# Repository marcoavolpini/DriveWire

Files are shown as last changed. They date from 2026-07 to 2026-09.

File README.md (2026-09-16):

# DriveWire

### A hardware-tested ESP32-S3 rover for embedded control, vehicle telemetry, and power-electronics development

DriveWire is a scaled-down electric vehicle test platform built to take an embedded system from breadboard bring-up to a custom PCB running FreeRTOS software. The current prototype drives two brushed DC motors, measures electrical and distance telemetry, and runs sensor acquisition in a periodic FreeRTOS task. Development is now focused on replacing the lossy prototype power path with a protected 2S LiPo power architecture that has been fully designed in Altium.

> **Status - September 2026:** the breadboard prototype and core firmware have been exercised on hardware. The custom power schematic is completed and needs to be laid out, fabricated, and validated. Telemetry currently runs over serial; Wi-Fi control and a browser dashboard are planned.

<p align="center">
  DriveWire ESP32-S3 rover prototype
</p>

## Engineering snapshot

| Area | Implemented and tested | In progress / next |
|---|---|---|
| Embedded firmware | PlatformIO/Arduino firmware, bidirectional motor control, braking/coasting, 17.5 kHz PWM, INA219 and VL53L0X drivers | Control interface, system-level safety logic, encoder feedback |
| Real-time telemetry | 100 ms FreeRTOS sensor task, single-item queue, voltage/current/power/distance state, last-valid-data behavior on failed reads | Recovery after sensor power cycling, telemetry transport over Wi-Fi |
| Electrical | 2S LiPo bench testing, current/voltage capture, stall-current characterization | Altium PCB power path, regulated 6 V and 3.3 V rails, component-value validation |
| Mechanical | Assembled 2WD chassis; three SolidWorks stand iterations; final stand printed in PLA and fit-tested | Dedicated sensor and battery mounting |

## Measured engineering evidence

- **Motor-current characterization:** two repeatable stall captures measured **1.3414 A** and **1.3308 A** using the onboard INA219. The firmware sampling period was reduced to 100 ms and the resulting trace was plotted in MATLAB to inform PCB current ratings.
- **Power-loss isolation:** during stall, INA219 telemetry fell to approximately **6.39 V**, but a DMM at the battery-connected rails measured only **7.78 V to 7.34 V**. This indicates that much of the observed drop is in the breadboard/prototype current path, which is now a design input for the PCB rather than an assumed battery failure.
- **PWM investigation:** a hardware sweep from 1 kHz to 18 kHz tied the audible motor tone to PWM carrier frequency. **17.5 kHz at 8-bit resolution** was selected and verified on both motors at full duty.
- **Sensor robustness:** failed INA219 or ToF reads mark the device offline without overwriting the previous valid telemetry. The VL53L0X produced reliable readings to approximately **1.3 m** under the tested indoor conditions.
- **Mechanical iteration:** the support stand progressed through three SolidWorks revisions before an approximately nine-hour PLA print; the finished part securely suspends the wheels for repeatable bench testing.

<p align="center">
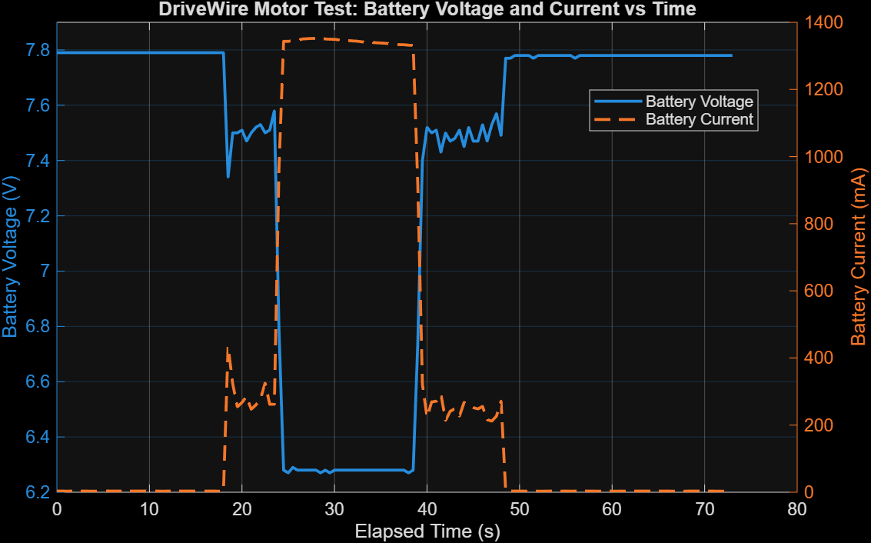
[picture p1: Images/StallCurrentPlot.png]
Measured DriveWire battery voltage and current during a motor stall test
  
</p>

## Current prototype architecture

```mermaid
flowchart LR
    LIPO[2S LiPo] --> PATH[Prototype power path]
    PATH --> INA[INA219 voltage/current sensing]
    PATH --> DRV[DRV8833 motor drive]
    DRV --> MOTORS[Left and right DC motors]
    ESP[ESP32-S3] -->|17.5 kHz PWM| DRV
    INA -->|I2C| ESP
    TOF[VL53L0X distance sensor] -->|I2C| ESP
    ESP --> TASK[100 ms FreeRTOS sensor task]
    TASK --> QUEUE[Latest-state queue]
    QUEUE --> SERIAL[Serial telemetry]
```

The firmware keeps commanded motor values, sensor readings, device status, and safety flags in a shared `DriveWireState`. The sensor task refreshes an independent state snapshot and publishes it through a one-element queue with `xQueueOverwrite()`, so the main loop reads a complete latest-value copy rather than partially updated telemetry.

## Custom power-system direction

The first Altium design translates lessons from the prototype into a board-level power path. The present schematic includes a 5 A fuse concept, PMOS reverse-polarity protection, a low-current mechanical switch controlling a power MOSFET, INA219 current sensing, and a TPS2121-based motor-rail concept with regulated 6 V and 3.3 V branches.

These are **design-stage features**, not validated hardware. Shunt value, I2C pull-ups, protection thresholds, regulator implementation, thermal performance, layout, and the complete safety review remain open before fabrication.

<p align="center">
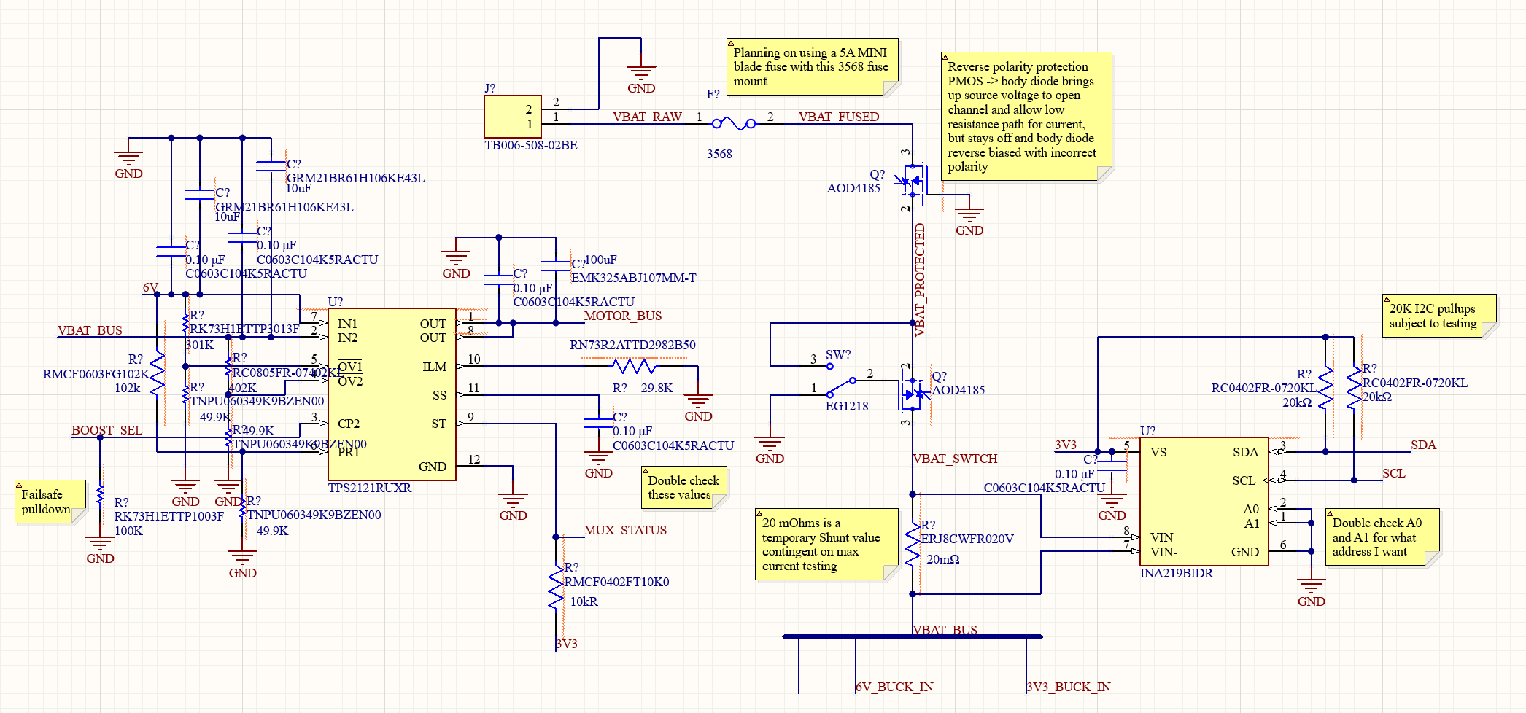
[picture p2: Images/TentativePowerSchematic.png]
In-progress DriveWire Altium power schematic
  
</p>

## Repository guide

| Path | Contents |
|---|---|
| [`Firmware/`](Firmware/) | PlatformIO project, motor control, sensor drivers, FreeRTOS task, and hardware test files |
| [`Hardware/`](Hardware/) | Altium project, power-design notes, datasheets, MATLAB test data, and plots |
| [`Mechanical/`](Mechanical/) | Chassis, battery wiring, and SolidWorks/3D-print documentation |
| [`BuildLog.md`](BuildLog.md) | Dated build history with test results, photos, and design decisions |
| [`Debugging.md`](Debugging.md) | Fault isolation, failed hypotheses, and resolved issues |
| [`BOM.md`](BOM.md) | Prototype bill of materials and status |

## Build the firmware

The firmware targets an **ESP32-S3-DevKitC-1** with Arduino through PlatformIO.

```bash
cd Firmware
pio run
pio device monitor -b 115200
```

The upload and monitor ports in [`Firmware/platformio.ini`](Firmware/platformio.ini) are workstation-specific and may need to be changed.

## Project scope

DriveWire is an active engineering project. The short-term milestones are to validate the power schematic, complete PCB layout, validate the protection and regulator stages, then integrate wireless control and closed-loop motion sensing. The distinction between bench-verified behavior and planned capability is maintained throughout this README and the build log.

---

<strong>Marco Volpini</strong><br>
Electrical Engineering, University of Waterloo

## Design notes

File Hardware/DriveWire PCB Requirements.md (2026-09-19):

**DriveWire PCB**

**6 V Buck Converter**

* Must take 6-8.4 V input from the LiPo pack
* Stall current was measured at consistently under 1.4 A with a 7.8 V charged battery, so being able to handle ideally >= 4 A 
* Needs to be pretty stable output for motor load (affects capacitor choice as well)

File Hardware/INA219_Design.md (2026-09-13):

# INA219 Hardware Design

I selected the INA219BIDR chip for this project because of its SOIC-8 form factor and of its higher accuracy as it is B grade rather than A. 

## Selecting a Shunt Resistor
First step is determining the expected max current I will need to sense.

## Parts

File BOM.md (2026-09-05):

# Bill of Materials

| Component | Purpose | Status |
|---|---|---|
| ESP32-S3 DevKitC-1-N8R8 | Main controller | In use |
| Pololu DRV8833 dual motor driver | Dual DC motor control | In use/testing |
| 2WD robot chassis | Mechanical platform | Assembled |
| DC gear motors | Propulsion | Wired |
| AA battery pack | Motor power | In use |
| Adafruit current sensor | Motor current measurement | Soldered, in use |
| Adafruit ToF sensor | Distance sensing | Soldered, in use |
| 22 AWG automotive wire | Motor and power wiring | In use |
| Heat shrink tubing | Joint insulation/strain relief | In use |
| LiPo 2S Battery Pack | Power source | In progress |

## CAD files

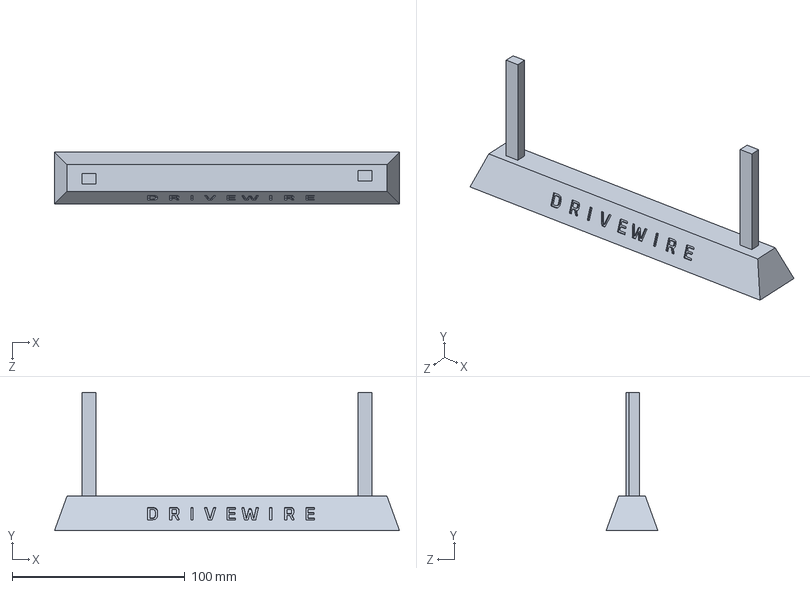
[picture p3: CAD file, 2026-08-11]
Mechanical/CAD/Support Stand/DriveWireStand.SLDPRT
200.0 x 80.0 x 30.0 mm

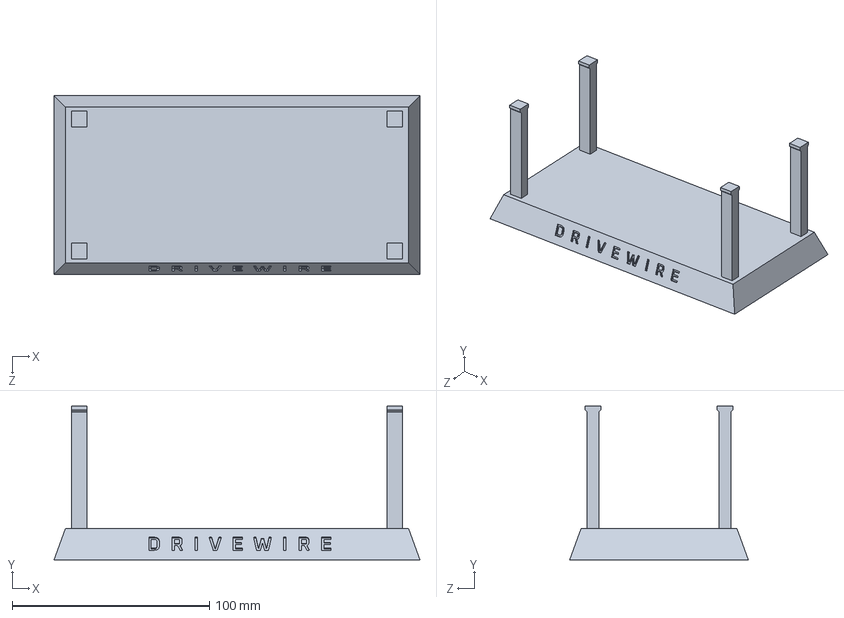
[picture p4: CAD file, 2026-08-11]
Mechanical/CAD/Support Stand/DriveWireStandv3.SLDPRT
185.6 x 78.0 x 90.6 mm

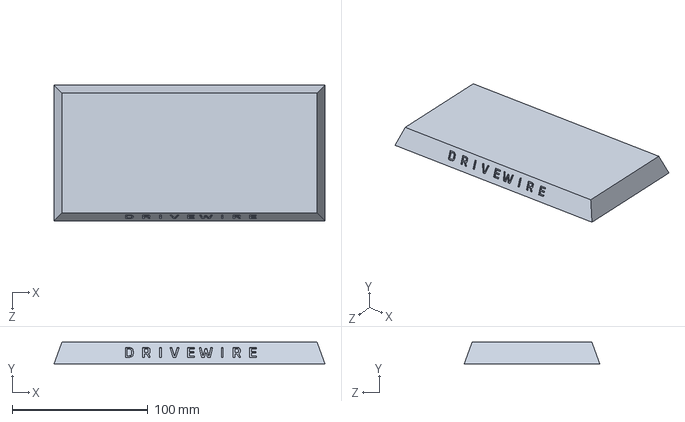
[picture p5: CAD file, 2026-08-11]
Mechanical/CAD/Support Stand/DriveWireStandv2.SLDPRT
200.0 x 16.0 x 100.1 mm

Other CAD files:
Mechanical/CAD/Support Stand/DriveWireStand.STL

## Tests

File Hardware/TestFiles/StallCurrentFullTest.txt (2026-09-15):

DriveWire I2C Firmware Starting...
Sensors Initialized...
Program starting...
Battery voltage: 7.79 V
Battery current: 3.40 mA
Distance in front: 90 mm
Battery voltage: 7.79 V
Battery current: 3.60 mA
Distance in front: 86 mm
Battery voltage: 7.79 V
Battery current: 3.10 mA
Distance in front: 87 mm
Battery voltage: 7.79 V
Battery current: 3.50 mA
Distance in front: 88 mm
Battery voltage: 7.79 V
Battery current: 3.50 mA
Distance in front: 88 mm
Battery voltage: 7.79 V
Battery current: 3.40 mA
Distance in front: 84 mm
Battery voltage: 7.79 V
Battery current: 3.50 mA
Distance in front: 88 mm
Battery voltage: 7.79 V
Battery current: 3.20 mA
Distance in front: 85 mm
Battery voltage: 7.79 V
Battery current: 3.10 mA
Distance in front: 87 mm
Battery voltage: 7.79 V
Battery current: 3.40 mA
Distance in front: 88 mm
Battery voltage: 7.79 V
Battery current: 3.30 mA
Distance in front: 89 mm
Battery voltage: 7.79 V
Battery current: 3.70 mA
Distance in front: 88 mm
Battery voltage: 7.79 V
Battery current: 3.30 mA
Distance in front: 85 mm
Battery voltage: 7.79 V
Battery current: 3.30 mA
Distance in front: 86 mm
Battery voltage: 7.79 V
Battery current: 3.30 mA
Distance in front: 90 mm
Battery voltage: 7.79 V
Battery current: 3.30 mA
Distance in front: 86 mm
Battery voltage: 7.79 V
Battery current: 3.50 mA
Distance in front: 88 mm
Battery voltage: 7.79 V
Battery current: 3.30 mA
Distance in front: 85 mm
Battery voltage: 7.79 V
Battery current: 3.30 mA
Distance in front: 88 mm
Battery voltage: 7.79 V
Battery current: 3.60 mA
Distance in front: 87 mm
Battery voltage: 7.79 V
Battery current: 3.40 mA
Distance in front: 87 mm
Battery voltage: 7.79 V
Battery current: 3.30 mA
Distance in front: 88 mm
Battery voltage: 7.79 V
Battery current: 3.30 mA
Distance in front: 87 mm
Battery voltage: 7.79 V
Battery current: 3.10 mA
Distance in front: 87 mm
Battery voltage: 7.79 V
Battery current: 3.40 mA
Distance in front: 87 mm
Battery voltage: 7.79 V
Battery current: 3.50 mA
Distance in front: 88 mm
Battery voltage: 7.79 V
Battery current: 3.30 mA
Distance in front: 86 mm
Battery voltage: 7.79 V
Battery current: 3.40 mA
Distance in front: 86 mm
Battery voltage: 7.79 V
Battery current: 3.40 mA
Distance in front: 87 mm
Battery voltage: 7.79 V
Battery current: 3.40 mA
Distance in front: 86 mm
Battery voltage: 7.79 V
Battery current: 3.30 mA
Distance in front: 90 mm
Battery voltage: 7.79 V
Battery current: 3.10 mA
Distance in front: 85 mm
Battery voltage: 7.79 V
Battery current: 3.50 mA
Distance in front: 87 mm
Battery voltage: 7.79 V
Battery current: 3.30 mA
Distance in front: 85 mm
Battery voltage: 7.79 V
Battery current: 3.40 mA
Distance in front: 86 mm
Battery voltage: 7.79 V
Battery current: 3.10 mA
Distance in front: 86 mm
Battery voltage: 7.79 V
Battery current: 3.30 mA
Distance in front: 86 mm
Battery voltage: 7.34 V
Battery current: 435.30 mA
Distance in front: 86 mm
Battery voltage: 7.50 V
Battery current: 322.80 mA
Distance in front: 88 mm
Battery voltage: 7.50 V
Battery current: 254.40 mA
Distance in front: 85 mm
Battery voltage: 7.51 V
Battery current: 267.40 mA
Distance in front: 85 mm
Battery voltage: 7.47 V
Battery current: 285.60 mA
Distance in front: 90 mm
Battery voltage: 7.50 V
Battery current: 247.10 mA
Distance in front: 87 mm
Battery voltage: 7.52 V
Battery current: 260.20 mA
Distance in front: 87 mm
Battery voltage: 7.53 V
Battery current: 277.50 mA
Distance in front: 88 mm
Battery voltage: 7.50 V
Battery current: 325.20 mA
Distance in front: 89 mm
Battery voltage: 7.51 V
Battery current: 262.10 mA
Distance in front: 87 mm
Battery voltage: 7.58 V
Battery current: 262.00 mA
Distance in front: 88 mm
Battery voltage: 6.79 V
Battery current: 965.50 mA
Distance in front: 87 mm
Battery voltage: 6.28 V
Battery current: 1343.40 mA
Distance in front: 80 mm
Battery voltage: 6.27 V
Battery current: 1343.10 mA
Distance in front: 87 mm
Battery voltage: 6.29 V
Battery current: 1345.60 mA
Distance in front: 77 mm
Battery voltage: 6.28 V
Battery current: 1346.10 mA
Distance in front: 77 mm
Battery voltage: 6.28 V
Battery current: 1350.20 mA
Distance in front: 84 mm
Battery voltage: 6.28 V
Battery current: 1351.10 mA
Distance in front: 79 mm
Battery voltage: 6.28 V
Battery current: 1351.80 mA
Distance in front: 80 mm
Battery voltage: 6.28 V
Battery current: 1351.90 mA
Distance in front: 80 mm
Battery voltage: 6.27 V
Battery current: 1352.40 mA
Distance in front: 82 mm
Battery voltage: 6.28 V
Battery current: 1350.40 mA
Distance in front: 82 mm
Battery voltage: 6.27 V
Battery current: 1349.50 mA
Distance in front: 81 mm
Battery voltage: 6.28 V
Battery current: 1349.40 mA
Distance in front: 81 mm
Battery voltage: 6.28 V
Battery current: 1347.40 mA
Distance in front: 82 mm
Battery voltage: 6.28 V
Battery current: 1346.40 mA
Distance in front: 79 mm
Battery voltage: 6.28 V
Battery current: 1345.40 mA
Distance in front: 82 mm
Battery voltage: 6.28 V
Battery current: 1344.50 mA
Distance in front: 78 mm
Battery voltage: 6.28 V
Battery current: 1343.60 mA
Distance in front: 83 mm
Battery voltage: 6.28 V
Battery current: 1341.70 mA
Distance in front: 82 mm
Battery voltage: 6.28 V
Battery current: 1340.90 mA
Distance in front: 80 mm
Battery voltage: 6.28 V
Battery current: 1340.10 mA
Distance in front: 81 mm
Battery voltage: 6.28 V
Battery current: 1339.10 mA
Distance in front: 85 mm
Battery voltage: 6.28 V
Battery current: 1338.20 mA
Distance in front: 77 mm
Battery voltage: 6.28 V
Battery current: 1337.50 mA
Distance in front: 79 mm
Battery voltage: 6.28 V
Battery current: 1336.10 mA
Distance in front: 79 mm
Battery voltage: 6.28 V
Battery current: 1334.00 mA
Distance in front: 81 mm
Battery voltage: 6.28 V
Battery current: 1333.50 mA
Distance in front: 81 mm
Battery voltage: 6.28 V
Battery current: 1333.10 mA
Distance in front: 79 mm
Battery voltage: 6.27 V
Battery current: 1331.90 mA
Distance in front: 80 mm
Battery voltage: 6.28 V
Battery current: 1330.90 mA
Distance in front: 79 mm
Battery voltage: 6.74 V
Battery current: 915.10 mA
Distance in front: 82 mm
Battery voltage: 7.40 V
Battery current: 321.80 mA
Distance in front: 84 mm
Battery voltage: 7.52 V
Battery current: 223.90 mA
Distance in front: 81 mm
Battery voltage: 7.50 V
Battery current: 269.10 mA
Distance in front: 85 mm
Battery voltage: 7.51 V
Battery current: 271.20 mA
Distance in front: 81 mm
Battery voltage: 7.43 V
Battery current: 292.20 mA
Distance in front: 87 mm
Battery voltage: 7.50 V
Battery current: 214.20 mA
Distance in front: 87 mm
Battery voltage: 7.47 V
Battery current: 241.20 mA
Distance in front: 82 mm
Battery voltage: 7.48 V
Battery current: 248.60 mA
Distance in front: 85 mm
Battery voltage: 7.51 V
Battery current: 226.90 mA
Distance in front: 82 mm
Battery voltage: 7.45 V
Battery current: 267.60 mA
Distance in front: 84 mm
Battery voltage: 7.52 V
Battery current: 260.70 mA
Distance in front: 82 mm
Battery voltage: 7.47 V
Battery current: 252.00 mA
Distance in front: 80 mm
Battery voltage: 7.47 V
Battery current: 248.30 mA
Distance in front: 80 mm
Battery voltage: 7.53 V
Battery current: 255.60 mA
Distance in front: 83 mm
Battery voltage: 7.47 V
Battery current: 216.00 mA
Distance in front: 83 mm
Battery voltage: 7.53 V
Battery current: 212.10 mA
Distance in front: 86 mm
Battery voltage: 7.57 V
Battery current: 226.80 mA
Distance in front: 87 mm
Battery voltage: 7.49 V
Battery current: 271.80 mA
Distance in front: 82 mm
Battery voltage: 7.77 V
Battery current: 3.50 mA
Distance in front: 85 mm
Battery voltage: 7.77 V
Battery current: 3.40 mA
Distance in front: 88 mm
Battery voltage: 7.78 V
Battery current: 3.50 mA
Distance in front: 85 mm
Battery voltage: 7.78 V
Battery current: 3.40 mA
Distance in front: 85 mm
Battery voltage: 7.78 V
Battery current: 3.30 mA
Distance in front: 83 mm
Battery voltage: 7.78 V
Battery current: 3.20 mA
Distance in front: 86 mm
Battery voltage: 7.77 V
Battery current: 3.20 mA
Distance in front: 84 mm
Battery voltage: 7.78 V
Battery current: 3.30 mA
Distance in front: 83 mm
Battery voltage: 7.78 V
Battery current: 3.10 mA
Distance in front: 86 mm
Battery voltage: 7.78 V
Battery current: 3.40 mA
Distance in front: 84 mm
Battery voltage: 7.78 V
Battery current: 3.30 mA
Distance in front: 86 mm
Battery voltage: 7.78 V
Battery current: 3.30 mA
Distance in front: 85 mm
Battery voltage: 7.78 V
Battery current: 3.20 mA
Distance in front: 86 mm
Battery voltage: 7.78 V
Battery current: 3.50 mA
Distance in front: 85 mm
Battery voltage: 7.78 V
Battery current: 3.20 mA
Distance in front: 85 mm
Battery voltage: 7.77 V
Battery current: 3.40 mA
Distance in front: 81 mm
Battery voltage: 7.78 V
Battery current: 3.40 mA
Distance in front: 86 mm
Battery voltage: 7.78 V
Battery current: 3.30 mA
Distance in front: 83 mm
Battery voltage: 7.78 V
Battery current: 3.40 mA
Distance in front: 84 mm
Battery voltage: 7.78 V
Battery current: 3.40 mA
Distance in front: 85 mm
Battery voltage: 7.78 V
Battery current: 3.10 mA
Distance in front: 83 mm
Battery voltage: 7.78 V
Battery current: 3.10 mA
Distance in front: 83 mm
Battery voltage: 7.78 V
Battery current: 3.30 mA
Distance in front: 83 mm
Battery voltage: 7.78 V
Battery current: 3.30 mA
Distance in front: 84 mm
Battery voltage: 7.78 V
Battery current: 3.20 mA
Distance in front: 86 mm
Battery voltage: 7.78 V
Battery current: 3.40 mA
Distance in front: 83 mm
Battery voltage: 7.78 V
Battery current: 3.10 mA
Distance in front: 86 mm
Battery voltage: 7.78 V
Battery current: 3.20 mA
Distance in front: 83 mm
Battery voltage: 7.78 V
Battery current: 3.40 mA
Distance in front: 87 mm
Battery voltage: 7.78 V
Battery current: 3.40 mA
Distance in front: 84 mm
Battery voltage: 7.78 V
Battery current: 3.30 mA
Distance in front: 82 mm
Battery voltage: 7.78 V
Battery current: 3.50 mA
Distance in front: 87 mm
Battery voltage: 7.78 V
Battery current: 3.40 mA
Distance in front: 83 mm
Battery voltage: 7.78 V
Battery current: 3.50 mA
Distance in front: 85 mm
Battery voltage: 7.78 V
Battery current: 3.30 mA
Distance in front: 88 mm
Battery voltage: 7.78 V
Battery current: 3.60 mA
Distance in front: 85 mm
Battery voltage: 7.78 V
Battery current: 3.10 mA
Distance in front: 82 mm
Battery voltage: 7.78 V
Battery current: 3.20 mA
Distance in front: 84 mm
Battery voltage: 7.78 V
Battery current: 3.20 mA
Distance in front: 84 mm
Battery voltage: 7.78 V
Battery current: 3.20 mA
Distance in front: 85 mm
Battery voltage: 7.78 V
Battery current: 3.50 mA
Distance in front: 86 mm
Battery voltage: 7.78 V
Battery current: 3.30 mA
Distance in front: 83 mm
Battery voltage: 7.78 V
Battery current: 3.30 mA
Distance in front: 84 mm
Battery voltage: 7.78 V
Battery current: 3.20 mA
Distance in front: 85 mm
Battery voltage: 7.78 V
Battery current: 3.30 mA
Distance in front: 87 mm
Battery voltage: 7.78 V
Battery current: 3.30 mA
Distance in front: 83 mm
Battery voltage: 7.78 V
Battery current: 3.10 mA
Distance in front: 86 mm
Battery voltage: 7.78 V
Battery current: 3.00 mA
Distance in front: 84 mm
Battery voltage: 7.78 V
Battery current: 3.20 mA
Distance in front: 86 mm
Battery voltage: 7.78 V
Battery current: 3.40 mA

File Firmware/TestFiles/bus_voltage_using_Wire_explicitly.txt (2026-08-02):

#include <Arduino.h> 

#include <motors.h>
#include <sensors.h>
#include <serial_interface.h>
#include <drivewire_state.h>

#include <Wire.h>

DriveWireState state;

constexpr int SDA_PIN = 7;
constexpr int SCL_PIN = 15;

void setup(){
  Serial.begin(115200);
  delay(1000);

  Serial.println("DriveWire I2C Firmware Starting...");

  Wire.begin(SDA_PIN, SCL_PIN);
}

void loop() {

  delay(1000);

  // getting the ESP32 ready to start by sending the INA219 address and a Write bit
  Wire.beginTransmission(0x40);

  Wire.write(0x2); // queues the desired register to send to the INA219 (for bus voltage)

  Wire.endTransmission(false); // false tells ESP32 not to send STOP
  // this sends everything and gets ACK, returns transmission result

  if (Wire.requestFrom(0x40, 2) != 2) { return; }
  // sends 0x40 again, and a read bit. Wants 2 bytes of data from the register.

  uint8_t MSB = Wire.read();
  uint8_t LSB = Wire.read();

  uint16_t MSB_shifted = (MSB << 8);  // bitshift MSB by 8 to make room for the LSB
  uint16_t rawBusVoltage = (MSB_shifted | LSB);

  uint16_t voltageCounts = (rawBusVoltage >> 3); // shave off the status bits

  float busVoltage = (voltageCounts * 0.004); // multiply the voltage count by 4 mV for total

  Serial.println(busVoltage);

  delay(2000);

}

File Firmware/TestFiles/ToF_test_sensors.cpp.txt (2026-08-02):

#include <Arduino.h> 

#include <motors.h>
#include <sensors.h>
#include <serial_interface.h>
#include <drivewire_state.h>

DriveWireState state;

void setup(){
  Serial.begin(115200);
  delay(1000);

  Serial.println("DriveWire Motor and Sensor Firmware Starting...");

  initializeMotors();
  initializeSensors(state);

}

void loop() {

  delay(1000);

  // first sampled reading

  if(refreshDistanceTelemetry(state)) {
    
    Serial.print("Distance in front of chassis in mm: ");
    Serial.println(state.distanceMm);

  } else if(!state.tofOnline) { 
    Serial.println("VL53L0X Offline");
    Serial.println("Failed to update electrical telemetry");

    Serial.println("Last valid reading: ");
    Serial.println(state.distanceMm);
  } else {
    Serial.println("Invalid measurement taken; object could be too far");

    Serial.println("Last valid reading: ");
    Serial.println(state.distanceMm);
  }

}

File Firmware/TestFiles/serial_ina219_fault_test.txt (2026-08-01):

#include <Arduino.h> 

#include <motors.h>
#include <sensors.h>
#include <serial_interface.h>
#include <drivewire_state.h>

DriveWireState state;

void setup(){
  Serial.begin(115200);
  delay(1000);

  Serial.println("DriveWire Motor and Sensor Firmware Starting...");

  initializeMotors();
  initializeSensors(state);

}

void loop() {

  delay(1000);

  // first sampled reading

  if(refreshElectricalTelemetry(state)) {
    
    Serial.print("Battery voltage at rest in V: ");
    Serial.println(state.batteryVoltageV);

    Serial.print("Battery current at rest in mA: ");
    Serial.println(state.currentMa);

    Serial.print("System power at rest in mW: ");
    Serial.println(state.powerMw);

  } else{
    if (!state.ina219Online) { Serial.println("INA219 Offline");}
    if (!state.tofOnline) { Serial.println("VL53L0X Offline");}

    Serial.println("Failed to update electrical telemetry");
  }

  delay(4000);

  if(refreshElectricalTelemetry(state)) { // unplug sensor before this to see error
    
    Serial.print("Battery voltage at rest in V: ");
    Serial.println(state.batteryVoltageV);

    Serial.print("Battery current at rest in mA: ");
    Serial.println(state.currentMa);

    Serial.print("System power at rest in mW: ");
    Serial.println(state.powerMw);

  } else{
    if (!state.ina219Online) { Serial.println("INA219 Offline");}
    if (!state.tofOnline) { Serial.println("VL53L0X Offline");}

    Serial.println("Failed to update electrical telemetry");
  }

  delay(3000);

  // to confirm the values did not change after an errored refresh
  Serial.print("Battery voltage unchanged after sensor error in V: ");
  Serial.println(state.batteryVoltageV);

  Serial.print("Battery current unchanged after sensor error in mA: ");
  Serial.println(state.currentMa);

  Serial.print("System power unchanged after sensor error in mW: ");
  Serial.println(state.powerMw);

}

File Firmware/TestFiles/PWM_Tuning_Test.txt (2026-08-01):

#include <Arduino.h> 

#include <motors.h>
#include <sensors.h>
#include <serial_interface.h>
#include <drivewire_state.h>

DriveWireState state;

void setup(){
  Serial.begin(115200);
  delay(1000);

  Serial.println("DriveWire Motor Firmware Starting...");

  initializeMotors();

  coastMotors(state);

  Serial.println("Motor Module Initialized");
}

void loop() {

  delay(1000);

  drive(state, 255, 255);
  delay(3000);
  coastMotors(state);

  delay(3000);

}

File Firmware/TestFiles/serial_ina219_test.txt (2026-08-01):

#include <Arduino.h> 

#include <motors.h>
#include <sensors.h>
#include <serial_interface.h>
#include <drivewire_state.h>

DriveWireState state;

void setup(){
  Serial.begin(115200);
  delay(1000);

  Serial.println("DriveWire Motor and Sensor Firmware Starting...");

  initializeMotors();
  initializeSensors(state);

}

void loop() {

  delay(1000);

  // first sampled reading

  if(refreshElectricalTelemetry(state)) {
    
    Serial.print("Battery voltage at rest in V: ");
    Serial.println(state.batteryVoltageV);

    Serial.print("Battery current at rest in mA: ");
    Serial.println(state.currentMa);

    Serial.print("System power at rest in mW: ");
    Serial.println(state.powerMw);

  }

  delay(2000);

  drive(state, 255, 255);

  delay(1000);

  if(refreshElectricalTelemetry(state)) {
    
    Serial.print("Battery voltage at full speed in V: ");
    Serial.println(state.batteryVoltageV);

    Serial.print("Battery current at full speed in mA: ");
    Serial.println(state.currentMa);

    Serial.print("System power at full speed in mW: ");
    Serial.println(state.powerMw);

  }

  delay(2000);
  coastMotors(state);

  delay(5000);

}

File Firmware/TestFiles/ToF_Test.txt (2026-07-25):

#include <Arduino.h>
#include <Wire.h>
#include <Adafruit_VL53L0X.h>

// pin assignments

constexpr int I2C_SDA_PIN = 7;
constexpr int I2C_SCL_PIN = 15;

constexpr int TOF_XSHUT_PIN = 14;

constexpr uint8_t TOF_I2C_ADDRESS = 0x29;

// create an instance of the VL53L0X sensor object

Adafruit_VL53L0X tof;

// setup

void setup() {

  Serial.begin(115200);
  delay(1000);

  Serial.println();
  Serial.println("DriveWire VL53L0X Test Starting");

  // set XSHUT as an output
  pinMode(TOF_XSHUT_PIN, OUTPUT);

  // toggle XSHUT to reset sensor 
  digitalWrite(TOF_XSHUT_PIN, LOW);
  delay(10);

  digitalWrite(TOF_XSHUT_PIN, HIGH); 
  delay(10);

  Serial.println("VL53L0X hardware reset complete"); 

  // initialize I2C bus communication

  Wire.begin(I2C_SDA_PIN, I2C_SCL_PIN);
  Serial.println("I2C bus initialized");

  // initialize the sensor

  if (!tof.begin(TOF_I2C_ADDRESS, false, &Wire)) {

    Serial.println("Failed to initialize sensor");

    while (true) {
      delay(100);
    }
  }

  Serial.println("Sensor successfully initialized");
  Serial.println("Beginning distance measurements");
  Serial.println();

}

// loop
void loop() {
VL53L0X_RangingMeasurementData_t measurement; 

// request a measurement
tof.rangingTest(&measurement, false); // address of data to fill, debug flag

if (measurement.RangeStatus != 4) { // if not out of range
  Serial.print("Distance (mm): ");
  Serial.print(measurement.RangeMilliMeter);
  Serial.print("mm | ");
  Serial.print(measurement.RangeMilliMeter / 10.0);
  Serial.println(" cm");
} else {
  Serial.println("Out of range");
}

delay(1000); // wait 1 second before next measurement
}

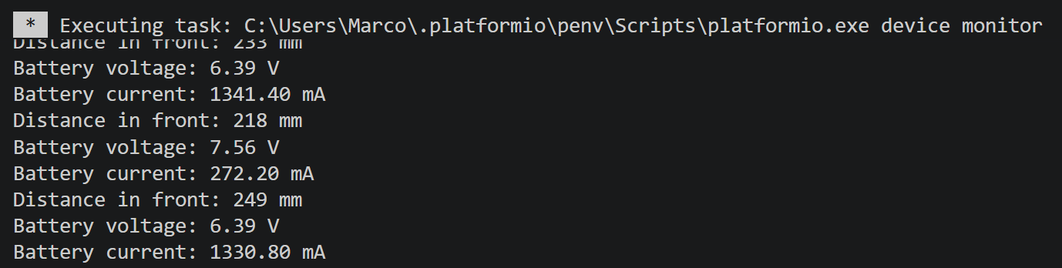
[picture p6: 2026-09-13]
Images/StallCurrentLiPoTest.png

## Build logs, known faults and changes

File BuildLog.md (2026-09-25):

## June 12th

All parts came in. Assembled mechanical [chassis](https://github.com/marcoavolpini/DriveWire/blob/main/Chassis.md).

## June 13th

Ran basic code on ESP32 board to show it is communicating properly with my computer over serial. 

## June 14th

Soldered dual motor driver board, and wired basic powertrain circuitry. Ran code to spin a motor, and touched two wires against contacts. Confirmed by doing so that the motor will go forward, and reverse based on the code written. 

## June 29th

Soldered 22 AWG automotive wire to the motor terminals, and wrapped joints in heat shrink wrap. Zip tied cables as needed to reduce strain on joints and keep good organization. 

Also soldered the current sensor board and time of flight sensor board. Soldered jumper wires to the battery pack with heat shrink at the joint for easy connection to power source. Battery pack secured to underside of chassis for lower centre of gravity, and breadboard mounted to top of chassis with adhesive. 

Wired up the full circuit minus the ToF sensor, and created much more in depth code that allows for user input in order to test circuit function. 

Ran into an issue where there was an audible buzzing, and no motor movement when expected with input. After some tinkering, I discovered that the PWM (pulse-width modulation) set at 90 was too low to overcome static friction, and the default frequency of 1kHz was causing the motor windings to vibrate and a frequency audible to the human ear. I adjusted the PWM duty value to 140 and this solved the issue. 

I now have a bug where one motor functions perfectly as expected, but the other is not responding to any inputs. I have two dual motor driver boards, so i tested between the two. I got slightly different results, but neither perfectly drove both motors. I still have to go through some more debugging, but at this point I am suspicious of the motor driver board. 

<p align="center">
  
</p>

# July 1 - July 3
I learned SolidWorks with the goal of 3D printing a professional demo [support stand](https://github.com/marcoavolpini/DriveWire/blob/main/Mechanical/Support-Stand.md) for DriveWire. I need the wheels to be suspended off the ground so that I can debug and demo properly. By July 3rd, using reference planes, sketch tools, and the rib feature, along with basic structural analysis, this is the stand that I produced:

<p align="center">
  
</p>

Also sliced design, and started 3D printing process using black PLA on the Raise3D E2 printer. Supports off to avoid scarring small details, and a 9 hour estimated print time. 

# July 6
3D printer error occured, and print stopped early. I restarted the print and it is going well so far and is 83.5% complete. Here is an image of the progress: 

<p align="center">
  DriveWire support stand 3D printing
</p>

I noticed the bottom corners lifting slightly due to shrinkage during cooling. The part will likely be functional, but for future iterations I will explore solutions such as increased temperature on the heating bed (was 65 degrees for this print), use of brim, and other print settings to improve first layer adhesion. 

# July 7th
I was able to pick up the successful print for the stand: 

<p align="center">
  DriveWire printed stand product
</p>

After testing, the chassis sits perfectly mounted on the stand and seems extremely stable. This will become the testbench where I can continue the debugging and bring-up process. Next step is to debug one motor not recieving power. 

# July 8th
Began debugging the issue where one motor isn't recieving power. 
Debugging extended video: [DriveWire V1 Debugging - Motor Power Issues](https://youtu.be/vDU9MoDfNq8?si=B3OYoYzJ7QpWY6p5)

During previous tests, I confirmed that both DC motors function correctly, and that the 22 AWG automotive wire and soldered motor terminal connections are not the source of the issue.

The suspected failure point was the dual motor driver board. To isolate the issue, I tested whether the fault followed the ESP32 control inputs or stayed with the motor driver output channel.

Before debugging, only the left motor was receiving power. However, its polarity was reversed relative to the firmware command.

First, I swapped the motor driver input signals. After this change, the left motor still ran, but its polarity changed. The right motor remained off. This suggested that the ESP32 control signals were not the main issue, since changing the input mapping affected the working motor but did not restore the inactive motor.

Next, I swapped the motor outputs. After swapping the outputs, the left motor no longer worked, while the right motor began working with reversed polarity. This confirmed that the fault stayed with one output channel of the motor driver board, rather than following the motor, wiring, or ESP32 control signals.

I inspected the driver board visually, but did not find any obvious solder bridges or damaged connections. The issue may be internal to the H-bridge or motor driver IC.

As a temporary workaround, I added the backup dual motor driver board. This second board also appears to have only one fully functional output channel, so each board is now driving one motor using its working channel. Both boards are powered from the same motor supply rail, which was approximately 6.24 V during testing, and both boards share a common ground with the ESP32.

With this setup, both wheels now spin correctly, and the forward, reverse, and pulse commands function as intended.

### New bug discovered: 
The turning commands are currently producing incorrect behavior.

For the right turn command, R, the left wheel spins backward, which suggests its polarity or logic is inverted. However, the right wheel also spins backward.

For the left turn command, L, the right wheel still spins backward, while the left wheel spins forward. The left wheel behavior appears to be an inverted polarity issue, but the right wheel not changing direction between L and R suggests that there may also be a firmware mapping or command logic issue.

The next debugging step is to verify the motor direction mapping in firmware and create a simple truth table for each command, showing the expected and actual direction of each wheel.

| Command | Expected Left | Expected Right | Actual Left | Actual Right |
| --- | --- | --- | --- | --- |
| F | forward | forward | forward | forward |
| B | backward | backward | backward | backward |
| L | backward | forward | forward | backward |
| R | forward | backward | backward | backward |

# July 20th
I designed a first version of the schematic of the main battery power architecture in Altium for the first DriveWire custom PCB. 

<p align="center">
  
</p>

Battery power comes in through the 2-pin screw terminal connector rated for 300 V and 12 A as per UL standards, with 20mOhm contact resistance. The negative terminal goes to ground and the positive terminal immediately goes to the main fuse. 

For now, I chose the 3568 Keystone fuse holder while planning on using a 5 A MINI Blade Fuse from Littelfuse, rated for 32 V DC. Here is the TCC curve from the spec sheet (looking at the 5 A curve): 

<p align="center">
  
</p>

Then the fused battery voltage is fed into the drain of a AOD4185 PMOS. This MOSFET is being used for reverse polarity protection, if the battery were to be connected the wrong way. It works by connecting its gate to ground, so that if battery voltage is connected properly, it brings VD high, and allows current to flow through the transistor's body diode to bring up the voltage at the source, VS. As the source voltage increases via the body diode, |VGS| increases, which forms the low resistance channel allowing current to then properly flow through. If the battery was connected the wrong way initially, VD would be negative VBAT, and then the body diode would be reverse biased and no current would flow through to change VS. 

After the reverse polarity protection, I added one more AOD4185 PMOS for the main mechanical power switch. This is because the selected EG1218 slide switch is rated for only 200 mA at 30 VDC, so it is not suitable for carrying the several amps that the complete system could draw. Instead the mosfet handles the current and the SPDT switch controls gate biasing. When the SPDT switch is switched to ground, VGS is at its largest magnitude and the mosfet conducts current, however when the switch is switched to connect to the source, VGS is zero, and no current flows, shutting the circuit power off. 

I am currently considering adding the ability for the ESP32 WROOM module to shut down the main power electronically. 

Then we get to the main VBAT bus, which has just a bit under full battery voltage (with minor losses from the circuitry above), protected from major short circuit currents through the main fuse, reverse polarity connections through the reverse connected PMOS, and controlled by a main switch through a second PMOS. 

# July 23rd
Wired the ToF distance sensor board (VL53L1X board). 

<p align="center">
  
</p>

Secured the sensor to the front of the chassis facing forward to detect objects in front of DriveWire. Used a temporary adhesive, which has the sensor secured in the appropriate position, however I am realizing a 3D printed bracket to hold the sensor board in the future would be a much more satisfying solution.

I will now begin working on the firmware to test the sensor. 

Later I finished writing a simple test file stored in the project as a .txt file under the TestFiles folder. It prints distance in both mm and cm over serial taking measurements at a frequency of 1 Hz. Here are some of the readings from the test run: 

<p align="center">
  
</p>

I also tested the maximum range with the physical hardware: 

<p align="center">
  
</p>

Under the tested indoor conditions and target surface, reliable readings were observed up to approximately 1.3 m. DriveWire should be able to brake in that distance if an object is detected in its path, though more testing will need to be done to confirm. 

A video of this process can be found [here](https://youtube.com/shorts/BkFgAW3W1bs?feature=share).

# July 24th
Completed the firmware for motors.cpp and motors.h, and wrote a couple test files to confirm function of driving both motors, reversing, coasting and braking at different speeds. 

Also wrote a test file that compares breaking to coasting from full speed. The Brake command drives both motor terminals high, effectively shorting the winding and causing the Back EMF to resist any rotation in the wheels. 

I observed the brake command bringing the wheels to a stop much quicker and more aggresively than the coast command from full speed. 

# July 29th
I investigated an audible beeping noise produced by both motors during low duty PWM operation. The initial hypothesis was that the default PWM carrier frequency was within the audible range, causing periodic current and torque ripple to mechanically excite the motor windings, housing, or gearbox.

The existing motor-control implementation used analogWrite(), which implicitly configured the ESP32-S3 LEDC peripheral at approximately 1 kHz with 8-bit duty resolution. I replaced this with explicit LEDC configuration using ledcSetup(), ledcAttachPin(), and ledcWrite().

During implementation, I determined that the project uses Arduino-ESP32 core 2.0.17. An earlier attempt had followed the newer Arduino-ESP32 3.x API, which uses functions such as ledcAttach(). That API was incompatible with the installed 2.x framework and caused the previous implementation to fail. Updating the code to use the correct version-specific LEDC functions resolved the configuration issue.

The 8-bit resolution was preserved so that existing motor commands remained on the same 0–255 duty scale.

To test the hypothesis, I held the motor duty command constant and increased the PWM frequency while listening for changes in the motor tone.

| PWM frequency | Observed result |
| ---: | --- |
| 1 kHz | Clearly audible baseline tone |
| 2 kHz | Tone increased to approximately twice the original pitch |
| 4 kHz | Higher-pitched audible tone |
| 8 kHz | Audible, but significantly higher pitched |
| 12 kHz | Faintly audible |
| 17 kHz | Barely audible |
| 17.5 kHz | Effectively unnoticeable during testing |
| 18 kHz | Effectively inaudible |

The observed tone consistently increased with PWM frequency, strongly supporting the hypothesis that the noise was caused by PWM-driven electromechanical vibration.

A PWM frequency of **17.5 kHz** was selected as the current operating point because it was effectively inaudible during testing while remaining slightly below 18 kHz to avoid introducing unnecessary switching losses in the motor driver. Both motors were also tested at the maximum 8-bit duty command of `255`, and both operated correctly at the new frequency.

This change resolved the audible motor noise issue and replaced the implicit Arduino PWM configuration with an explicit, configurable motor-control implementation.

### Follow-up testing

Further testing will compare the minimum reliable motor-starting duty at 1 kHz and 17.5 kHz. This will help determine whether the higher switching frequency affects low-speed startup behaviour and whether a minimum-duty mapping or short startup-boost strategy is required.

# July 31
Wrote `sensors.h` and began `sensors.cpp`. For DriveWire V1, I currently have two sensors for telemetry: The INA219 gives me both bus voltage and current readings, and the VL53L0X gives me ToF distance in mm directly outward from the front of the chassis. 

Today I wrote the firmware to refresh system current, voltage and power data through the INA219 sensor using I2C protocol. I also wrote a simple test file to see its function under normal healthy operation: 

<p align="center">
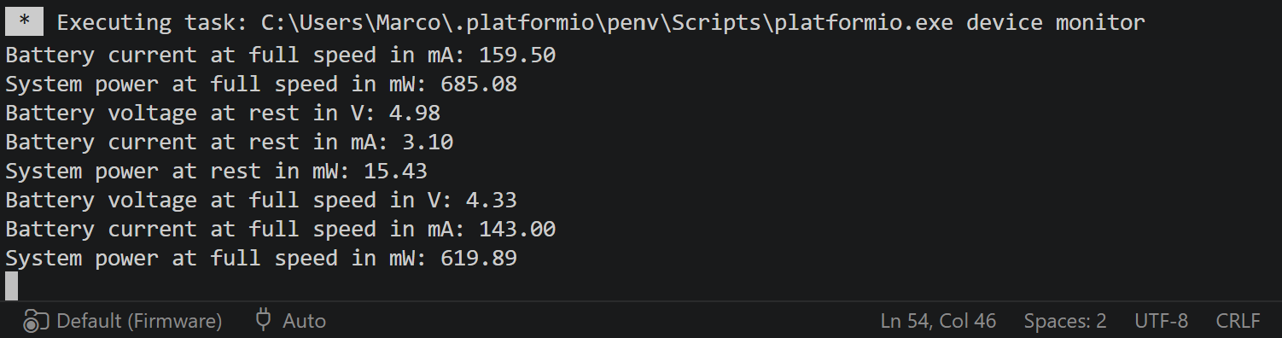
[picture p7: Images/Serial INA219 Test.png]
  
</p>

Also wrote a test file to test the fault functionality of sensors.cpp for the INA219 sensor. I let it run one telemetry data refresh, then I unplugged the sensor from its 3v3 power supply. It then reported the fault as expected, first outputting three Wire related errors, then confirming that the INA219 is offline, and that the refresh failed:

<p align="center">
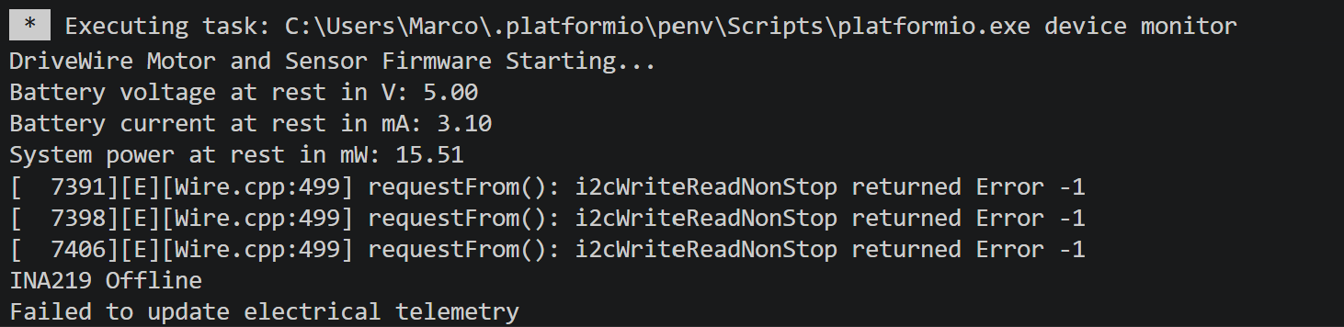
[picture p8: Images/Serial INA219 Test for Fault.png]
  
</p>

# August 1
Updated sensors.cpp `refreshElectricalTelemetry()` so it now immediately returns false after first failed poll, and the test file now shows values previous to sensor failure remain saved: 

<p align="center">
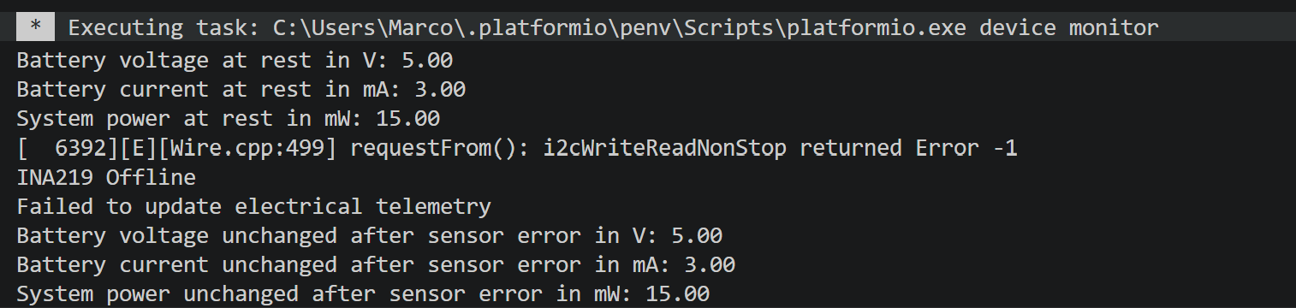
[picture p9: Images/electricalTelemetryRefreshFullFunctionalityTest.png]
  
</p>

Build the `refreshDistanceTelemetry()` function, as well as the `refreshAllSensors()` function. That is the completed version of sensors.cpp for DriveWire V1, subject to testing of course. In the reasonably near future adding encoders would be very beneficial, in which case this file will be updated. 

I also designed a ToF telemetry  test file. 

I tested the ToF telemetry by giving it valid measurements first, then gave it a distance outside its range (confirming it retains the last valid value and outputs a message about an invalid measurement), and then unpluging it to see it update its status to offline. Everything seems good. I did note a difference between the INA219 and teh VL53L0X upon connecting them back to power during these tests. Read more about that in the [debugging](https://github.com/marcoavolpini/DriveWire/blob/main/Debugging.md) file. 

I also wrote a file to read one of the INA219 registers using only Wire for I2C, just as a debugging file for my own use. I appended a similar function to `sensors.cpp`. I will likely remove this and keep both as `.txt` files in my `TestFiles` folder, to avoid mixing use of libraries and lower level handwritten I2C firmware. Outputs of this explicit implementation resulted in the same voltage values as reading through the Adafruit library: 

<p align="center">
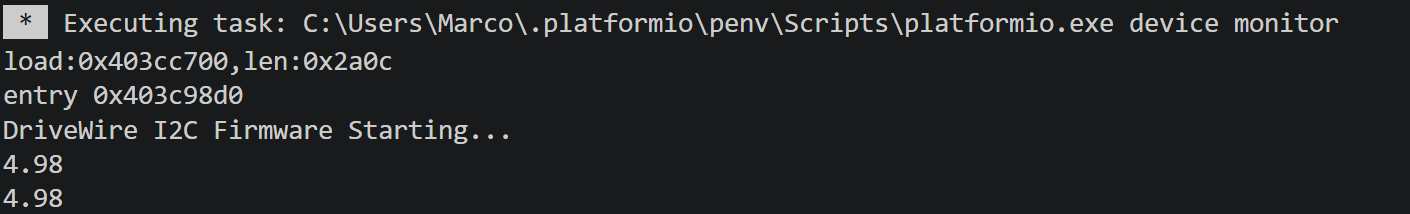
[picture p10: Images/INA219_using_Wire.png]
  
</p>

# August 10
Updated main.cpp to prepare for operation over serial, and FreeRTOS implementation. Also added [Hardware](https://github.com/marcoavolpini/DriveWire/tree/main/Hardware) folder containing early existing Altium PCB files, as well as a mechanical CAD folder containing the existing [Support Stand CAD](https://github.com/marcoavolpini/DriveWire/tree/main/Mechanical/CAD/Support%20Stand). 

# August 13
Implemented the first RTOS task in DriveWire using FreeRTOS. A dedicated Sensor Task now refreshes the INA219 and VL53L0X every 1.5 seconds using `xTaskDelayUntil()`, then publishes the latest `DriveWireState` snapshot through a single item FreeRTOS queue. The Arduino `loop()` receives and prints an independent copy, preventing it from reading the shared state while sensor data is being updated (avoids data race). The firmware builds successfully and was verified with live sensor telemetry.

# September 12
Added the INA219BIDR chip and surrounding circuitry with a tentative 20 mOhm shunt value and 20K I2C pullups (ToF already has SDA and SCL pullups). 

Created the main VBAT_BUS that is fused, switched and protected from reverse polarity. This will feed into a 3V3 buck converter to power sensors and the ESP32 WROOM module. It also feeds a TPS2121 power mux IC both directly and through a 6V buck converter for motor power and a hardware boost mode (rather than PWM control which is not as perfect of a solution. 

<p align="center">
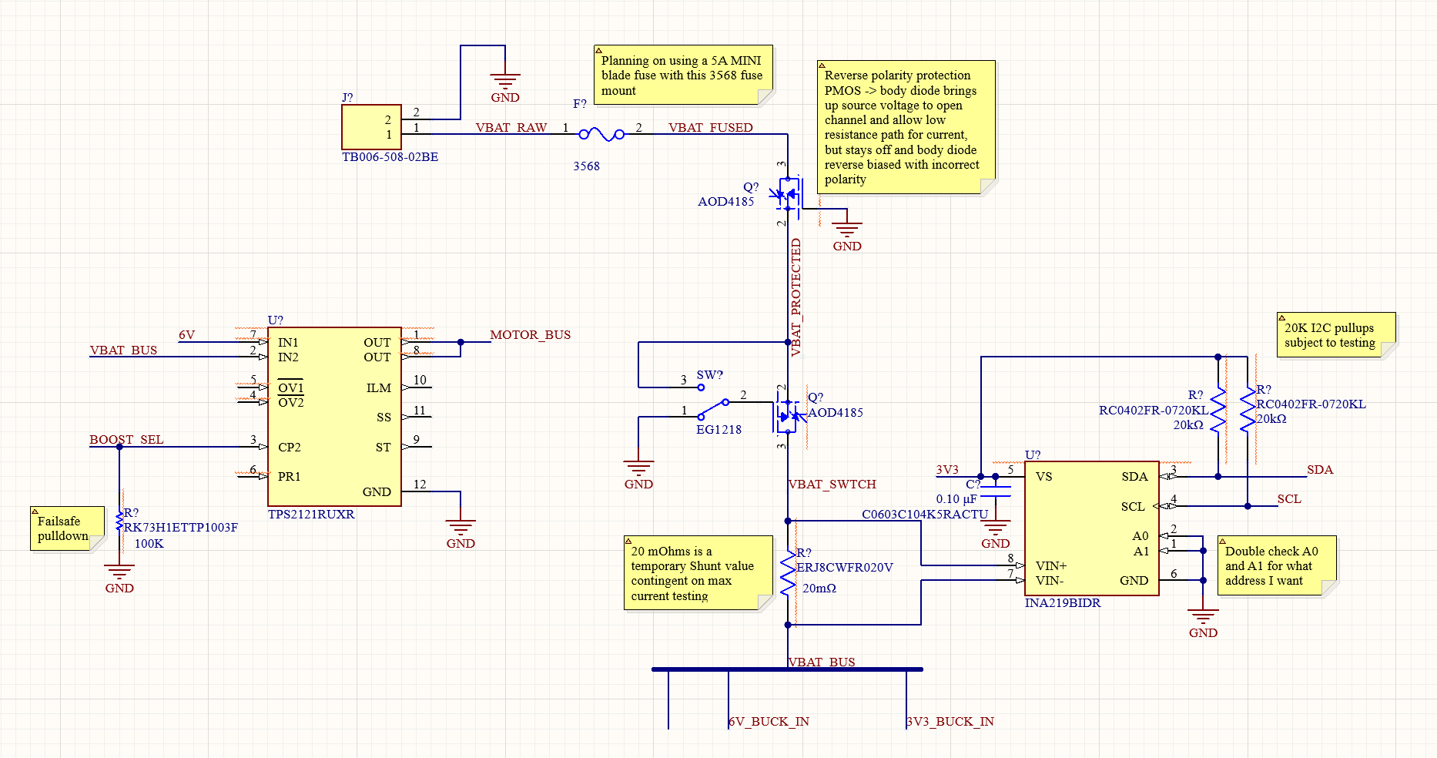
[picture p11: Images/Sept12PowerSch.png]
  
</p>

Also tested the system stall current using the new 2S LiPo pack charged to around 7.8 V unloaded (value from testing with my DMM). Can view a YouTube video of the test [here](https://youtu.be/42B50RET46Q?si=w4cIeANYq-4YvmkY). 

The terminal output was as such: 
`DriveWire I2C Firmware Starting... 
Sensors Initialized... 
Program starting... 
Battery voltage: 0.89 V 
Battery current: -0.30 mA 
Distance in front: 315 mm 
Battery voltage: 7.50 V 
Battery current: 324.90 mA 
Distance in front: 139 mm 
Battery voltage: 7.51 V 
Battery current: 264.70 mA 
Distance in front: 319 mm 
Battery voltage: 7.50 V 
Battery current: 293.40 mA 
Distance in front: 233 mm 
Battery voltage: 6.39 V 
Battery current: 1341.40 mA 
Distance in front: 218 mm 
Battery voltage: 7.56 V 
Battery current: 272.20 mA 
Distance in front: 249 mm 
Battery voltage: 6.39 V 
Battery current: 1330.80 mA`

Only two stall currents were captured, with both readings being very similarly between 1.3 and 1.4 amps. This is helpful for PCB component selection when knowing what current ratings have acceptable overhead. 

Something I need to confirm in the future is why the battery sagged by ~1.2 V. It could very possibly be due to my prototype setup with jumpers and a breadboard, but I can confirm with my DMM measuring the power bus during a stall to see voltage. 

# September 14
I retested the stall current with the LiPo pack, and got similar values. This time, I also measured the power rails with a DMM to see if the ~1.2 V voltage drop seen by the INA219 was due to prototype imperfections and resistances, or if the battery was sagging a concerning amount. The power rails (connected directly to battery terminals), went from 7.78 V normal operation to 7.34 V during stall current. So the 6.39 V readings I have been seeing during these tests are due to losses in the circuitry rather than an issue with the battery. This inefficiency is expected to be entirely resolved by the PCB. 

*Todo: consider OV2 battery voltage interlock system with mosfet and microcontroller control*

I decreased the INA219 telemetry period to 0.1s and updated the test in main.cpp to get a stall current plot. Plotted it in MATLAB (relevant files found in Hardware > TestFiles): 

<p align="center">
  
</p>

I also completed the Power schematic with some tentative values upon further testing: 

<p align="center">
  
</p>

# September 22
Designing 6V buck converter circuit. Chose TPS62130ARGTR. 

# September 24
Almost finished 6V buck converter schematic. Made soft start capacitor decision, designed voltage divider with 130k and 20k ohm resistors for enough current for stability, without wasting too much energy or degrading thermal performance. All pins complete other than SW: 

<p align="center">
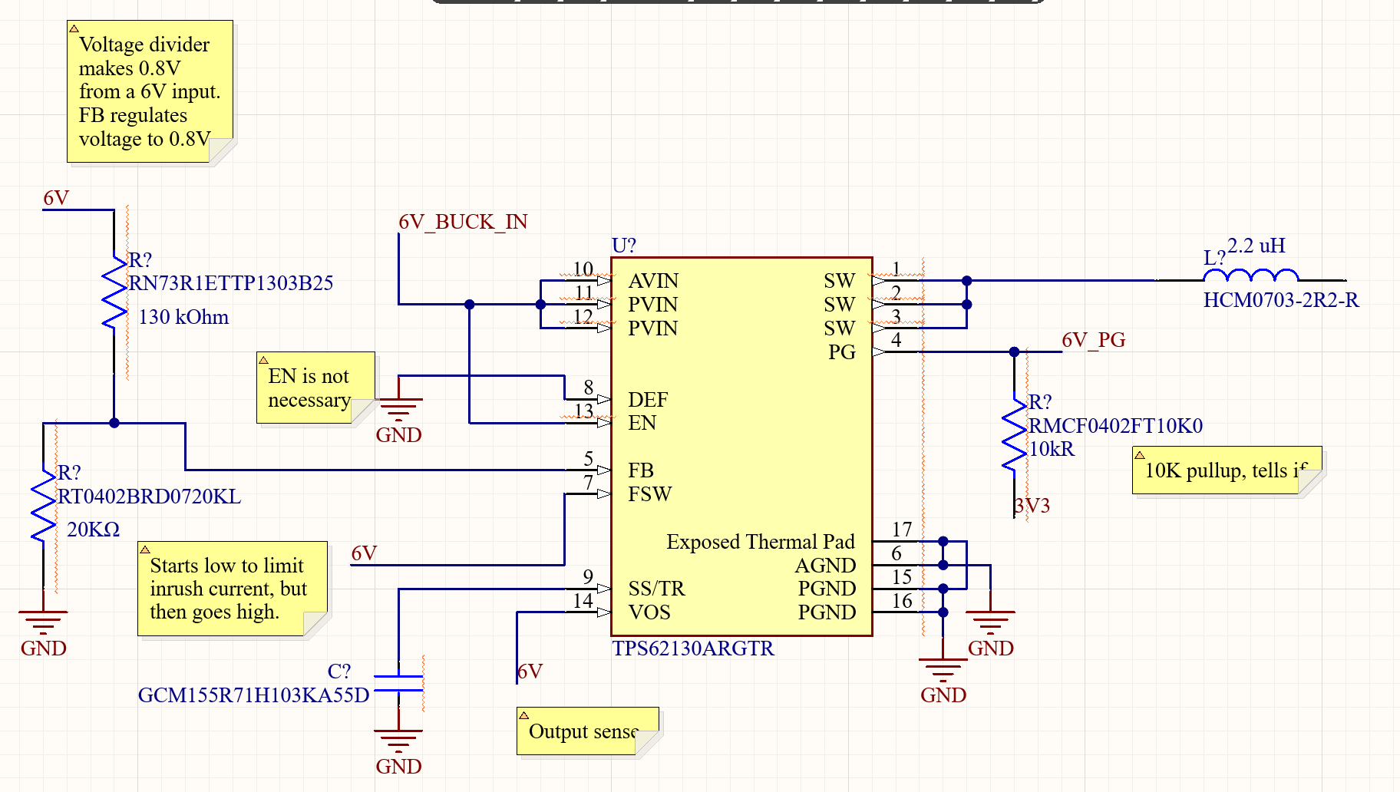
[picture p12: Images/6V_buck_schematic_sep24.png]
  
</p>

# September 25
Selected inductor based on saturation current, RMS current, DCR, size, shielding and other conditions determined necessary for the 6V buck design. Had to create a custom footprint referencing the datasheet: 

<p align="center">
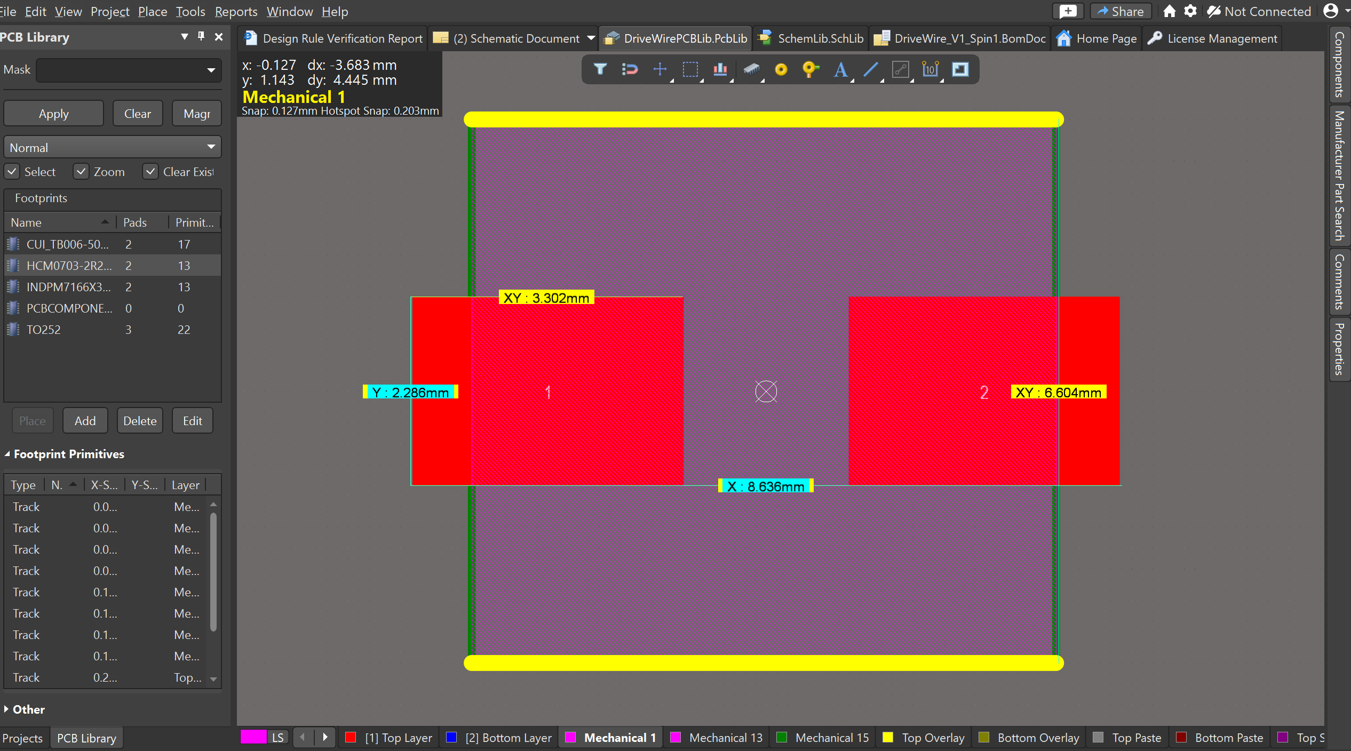
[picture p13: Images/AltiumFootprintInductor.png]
  
</p>

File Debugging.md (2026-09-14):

## June 29: Buzzing noise and no motor movement (Resolved July 29)

Ran into an issue where there was an audible buzzing, and no motor movement when expected with input. After some tinkering, I discovered that the PWM (pulse-width modulation) set at 90 was too low to overcome static friction, and the default frequency of 1kHz was causing the motor windings to vibrate and a frequency audible to the human ear. I adjusted the PWM duty cycle to 140, and this caused one wheel to spin and the buzzing sound to be much less noticeable. 

I now have a bug where one motor functions perfectly as expected, but the other is not responding to any inputs. I have two dual motor driver boards, so i tested between the two. I got slightly different results, but neither perfectly drove both motors. I still have to go through some more debugging, but at this point I am suspicious of the motor driver board.

*This has since been resolved on July 29th*

## July 7: Only one motor receiving power

Debugging extended video: [DriveWire V1 Debugging - Motor Power Issues](https://youtu.be/DzpZYJx54m0?si=vVjL2RTWoly1Th7c)

During previous tests, I confirmed that both DC motors function correctly, and that the 22 AWG automotive wire and soldered motor terminal connections are not the source of the issue.

The suspected failure point was the dual motor driver board. To isolate the issue, I tested whether the fault followed the ESP32 control inputs or stayed with the motor driver output channel.

Before debugging, only the left motor was receiving power. However, its polarity was reversed relative to the firmware command.

First, I swapped the motor driver input signals. After this change, the left motor still ran, but its polarity changed. The right motor remained off. This suggested that the ESP32 control signals were not the main issue, since changing the input mapping affected the working motor but did not restore the inactive motor.

Next, I swapped the motor outputs. After swapping the outputs, the left motor no longer worked, while the right motor began working with reversed polarity. This confirmed that the fault stayed with one output channel of the motor driver board, rather than following the motor, wiring, or ESP32 control signals.

I inspected the driver board visually, but did not find any obvious solder bridges or damaged connections. The issue may be internal to the H-bridge or motor driver IC.

As a temporary workaround, I added the backup dual motor driver board. This second board also appears to have only one fully functional output channel, so each board is now driving one motor using its working channel. Both boards are powered from the same motor supply rail, which was approximately 6.24 V during testing, and both boards share a common ground with the ESP32.

With this setup, both wheels now spin correctly, and the forward, reverse, and pulse commands function as intended.

### New bug discovered: 
The turning commands are currently producing incorrect behavior.

For the right turn command, R, the left wheel spins backward, which suggests its polarity or logic is inverted. However, the right wheel also spins backward.

For the left turn command, L, the right wheel still spins backward, while the left wheel spins forward. The left wheel behavior appears to be an inverted polarity issue, but the right wheel not changing direction between L and R suggests that there may also be a firmware mapping or command logic issue.

The next debugging step is to verify the motor direction mapping in firmware and create a simple truth table for each command, showing the expected and actual direction of each wheel.

| Command | Expected Left | Expected Right | Actual Left | Actual Right |
| --- | --- | --- | --- | --- |
| F | forward | forward | forward | forward |
| B | backward | backward | backward | backward |
| L | backward | forward | forward | backward |
| R | forward | backward | backward | backward |

# July 29th: PWM Frequency Testing and Audible Motor Noise Fix
I investigated the audible beeping noise produced by both motors during low duty PWM operation. The initial hypothesis was that the default PWM carrier frequency was within the audible range, causing periodic current and torque ripple to mechanically excite the motor windings, housing, or gearbox.

The existing motor-control implementation used analogWrite(), which implicitly configured the ESP32-S3 LEDC peripheral at approximately 1 kHz with 8-bit duty resolution. I replaced this with explicit LEDC configuration using ledcSetup(), ledcAttachPin(), and ledcWrite().

During implementation, I determined that the project uses Arduino-ESP32 core 2.0.17. An earlier attempt had followed the newer Arduino-ESP32 3.x API, which uses functions such as ledcAttach(). That API was incompatible with the installed 2.x framework and caused the previous implementation to fail. Updating the code to use the correct version-specific LEDC functions resolved the configuration issue.

The 8-bit resolution was preserved so that existing motor commands remained on the same 0–255 duty scale.

To test the hypothesis, I held the motor duty command constant and increased the PWM frequency while listening for changes in the motor tone.

| PWM frequency | Observed result |
| ---: | --- |
| 1 kHz | Clearly audible baseline tone |
| 2 kHz | Tone increased to approximately twice the original pitch |
| 4 kHz | Higher-pitched audible tone |
| 8 kHz | Audible, but significantly higher pitched |
| 12 kHz | Faintly audible |
| 17 kHz | Barely audible |
| 17.5 kHz | Effectively unnoticeable during testing |
| 18 kHz | Effectively inaudible |

The observed tone consistently increased with PWM frequency, strongly supporting the hypothesis that the noise was caused by PWM-driven electromechanical vibration.

A PWM frequency of **17.5 kHz** was selected as the current operating point because it was effectively inaudible during testing while remaining slightly below 18 kHz to avoid introducing unnecessary switching losses in the motor driver. Both motors were also tested at the maximum 8-bit duty command of `255`, and both operated correctly at the new frequency.

This change resolved the audible motor noise issue and replaced the implicit Arduino PWM configuration with an explicit, configurable motor-control implementation.

### Follow-up testing

Further testing will compare the minimum reliable motor-starting duty at 1 kHz and 17.5 kHz. This will help determine whether the higher switching frequency affects low-speed startup behaviour and whether a minimum-duty mapping or short startup-boost strategy is required.

# August 1: Distance Telemetry Offline Loop
After writing a test file for my distance telemetry code, I saw that everything worked as expected for valid measurements, and measurements out of range. After disconnecting the sensor from power, it handled it properly, updating the online status to offline, however after plugging the sensor back in, readins continued as though the sensor was offline. 

I now realize that this is because cutting the power to the breakout board also reset the I2C initialization done in the setup. So the sensor was on again, but not ready to communicate with the system. 

This means nothing is wrong with the firmware, however it does make me think I may want to consider trying `initializeSensors()` periodically if a sensor goes offline. 

I also noticed that the INA219 sensor begins transmitting data as normal when reconnected to power. I believe this is something to do with the Adafruit library for the INA219 writing to the calibration register everytime it tries to send data. Interesting to see the difference between this and the ToF board. 

# September 14
I tested stall current with the new 2S LiPo battery by having the motors on full power, and stopping them from spinning. I'd then read telemetry values of battery current and voltage from the onboard INA219 sensor. These are some of the values I got: 

`Battery voltage: 7.50 V` 
`Battery current: 324.90 mA`
`Distance in front: 139 mm` 
`Battery voltage: 7.51 V` 
`Battery current: 264.70 mA` 
`Distance in front: 319 mm` 
`Battery voltage: 7.50 V`
`Battery current: 293.40 mA` 
`Distance in front: 233 mm` 
`Battery voltage: 6.39 V` 
`Battery current: 1341.40 mA` 
`Distance in front: 218 mm` 
`Battery voltage: 7.56 V` 
`Battery current: 272.20 mA` 
`Distance in front: 249 mm` 
`Battery voltage: 6.39 V` 
`Battery current: 1330.80 mA`

I noticed that the battery voltage readings were dropping by around 1.2 V during stall current, which would be a concerning amount of battery sag. To see if this was the battery, or simply internal resistances in the prototype circuit, I conducted the stall current test again, this time also measuring the power rails with a DMM to see if the ~1.2 V voltage drop seen by the INA219 was due to prototype imperfections and resistances, or if the battery was sagging a concerning amount. The power rails (connected directly to battery terminals), went from 7.78 V normal operation to 7.34 V during stall current. So the 6.39 V readings I have been seeing during these tests are due to losses in the circuitry rather than an issue with the battery. This inefficiency is expected to be entirely resolved by the PCB.

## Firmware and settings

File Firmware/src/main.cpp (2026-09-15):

#include <Arduino.h> 

#include <motors.h>
#include <sensors.h>
#include <serial_interface.h>
#include <drivewire_state.h>

// including FreeRTOS libraries
#include <FreeRTOS.h>
#include <task.h>
#include <queue.h>

DriveWireState state;

// initializing a queue handle for the sensor task that holds a snapshot of sensor telemetry
// it is a pointer to a queue?
QueueHandle_t sensorQueue = nullptr;

// declaring sensorTask
void sensorTask(void* parameter);


void setup(){
  Serial.begin(115200);
  delay(1000);

  Serial.println("DriveWire I2C Firmware Starting...");

  initializeMotors();
  coastMotors(state);

  if (initializeSensors(state)) {Serial.println("Sensors Initialized...");}
  else { Serial.println(state.ina219Online); Serial.println(state.tofOnline);}



  // gonna create the queue and assign it to the handle initialized globally
  sensorQueue = xQueueCreate(1, sizeof(DriveWireState));

  if (sensorQueue == nullptr) {
    Serial.println("Failed to create sensor queue");

    Serial.println("The program will not run");
    for ( ; ; ) {
      vTaskDelay(pdMS_TO_TICKS(1000));
    }
  }

  // creating the sensor task
  BaseType_t taskResult = xTaskCreate(
    sensorTask, 
    "sensorTask", 
    4096, 
    &state, 
    1, 
    nullptr
  );

  // checking for successful sensor task creation
  if (taskResult != pdPASS) {
    Serial.println("Failed to create sensor task.");

    Serial.println("The program will not run");
    for ( ; ; ) {
      vTaskDelay(pdMS_TO_TICKS(1000));
    }
  }


  // actually initializeMotors is a void function so we can't currently check if successful

  Serial.println("Program starting...");
}

void loop() {

  DriveWireState receivedState;

  if (xQueueReceive(sensorQueue, &receivedState, 0) == pdTRUE) {
    Serial.print("Battery voltage: ");
    Serial.print(receivedState.batteryVoltageV);
    Serial.println(" V");  

    Serial.print("Battery current: ");
    Serial.print(receivedState.currentMa);
    Serial.println(" mA");

    Serial.print("Distance in front: ");
    Serial.print(receivedState.distanceMm);
    Serial.println(" mm");    
  }
  

  // better motor test

  static unsigned long lastMotorChange = 0;
  static bool motorsDriving = false;

  unsigned long currentTime = millis();

  if (!motorsDriving && currentTime-lastMotorChange >= 5000) {

    drive(state, 255, 255);

    motorsDriving = true;
    lastMotorChange = currentTime;
  } 
  else if (motorsDriving && currentTime - lastMotorChange >= 6000) {

    coastMotors(state);

    motorsDriving = false;
    lastMotorChange = currentTime;

  }
}

void sensorTask(void* parameter) {

  DriveWireState* sensorState = static_cast<DriveWireState*>(parameter);
    
  // making a TickType_t period
  // added pdMS_TO_TICKS to be sure 0.1s period
  const TickType_t sensorPeriod = pdMS_TO_TICKS(100);

  TickType_t lastWakeTime = xTaskGetTickCount();

  for ( ; ; ) {

    refreshAllSensors(*sensorState);

    xQueueOverwrite(sensorQueue, sensorState);

    //set the task period
    xTaskDelayUntil(&lastWakeTime, sensorPeriod);
  }


}

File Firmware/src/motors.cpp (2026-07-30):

#include <Arduino.h>

#include <motors.h>

// motor A, left motor
constexpr int LEFT_IN1_PIN = 8;
constexpr int LEFT_IN2_PIN = 3;

// motor B, right motor
constexpr int RIGHT_IN1_PIN = 10;
constexpr int RIGHT_IN2_PIN = 9;

constexpr uint32_t pwmFreq = 17500;

constexpr int L_IN1_CH = 1;
constexpr int L_IN2_CH = 2;
constexpr int R_IN1_CH = 3;
constexpr int R_IN2_CH = 4;

// initialize motors

void initializeMotors() {
    /*
    pinMode(LEFT_IN1_PIN, OUTPUT);
    pinMode(LEFT_IN2_PIN, OUTPUT);

    pinMode(RIGHT_IN1_PIN, OUTPUT); 
    pinMode(RIGHT_IN2_PIN, OUTPUT);

    analogWrite(LEFT_IN1_PIN, 0);
    analogWrite(LEFT_IN2_PIN, 0);

    analogWrite(RIGHT_IN1_PIN, 0);
    analogWrite(RIGHT_IN2_PIN, 0);
    */

    if ((ledcSetup(1, pwmFreq, 8) * ledcSetup(2, pwmFreq, 8) * ledcSetup(3, pwmFreq, 8) * 
ledcSetup(4, pwmFreq, 8))== 0){
        // considering making boolean error values like pwmSetupError but not sure
        return;
    }
    // should i add checks for all of these? is there an easier way to check? 
    ledcAttachPin(LEFT_IN1_PIN, L_IN1_CH);
    ledcAttachPin(LEFT_IN2_PIN, L_IN2_CH);

    ledcAttachPin(RIGHT_IN1_PIN, R_IN1_CH);
    ledcAttachPin(RIGHT_IN2_PIN, R_IN2_CH);

    // set all motors to rest
    ledcWrite(L_IN1_CH, 0);
    ledcWrite(L_IN2_CH, 0);

    ledcWrite(R_IN1_CH, 0);
    ledcWrite(R_IN2_CH, 0);
}

// left motor control

void setLeftMotor(DriveWireState& state, int16_t pwm) {
    
    pwm = constrain(pwm, -255, 255);

    if (pwm > 0) {
        // all these changed from analogWrite(GPIO, pwm) to this
        ledcWrite(L_IN1_CH, pwm); 
        ledcWrite(L_IN2_CH, 0);
    } 
    else if (pwm < 0) {
        ledcWrite(L_IN1_CH, 0);
        ledcWrite(L_IN2_CH, -pwm);
    } else {
        ledcWrite(L_IN1_CH, 0);
        ledcWrite(L_IN2_CH, 0);
    }

    state.leftMotorPwm = pwm;
}

// right motor control 

void setRightMotor(DriveWireState& state, int16_t pwm) {

    pwm = constrain(pwm, -255, 255);

    if (pwm > 0) {
        ledcWrite(R_IN1_CH, pwm);
        ledcWrite(R_IN2_CH, 0);
    } else if (pwm < 0) {
        ledcWrite(R_IN1_CH, 0);
        ledcWrite(R_IN2_CH, -pwm);
    } else {
        ledcWrite(R_IN1_CH, 0);
        ledcWrite(R_IN2_CH, 0);
    }

    state.rightMotorPwm = pwm;
}

// drive function using previous two blocks

void drive(DriveWireState& state, int16_t leftPwm, int16_t rightPwm) {

    setLeftMotor(state, leftPwm);
    setRightMotor(state, rightPwm);

}

// coast function using drive building block

void coastMotors( DriveWireState& state) {
    
    drive(state, 0, 0);

}

// brake function: full power on both motor inputs to lock wheels

void brakeMotors(DriveWireState& state) {

    ledcWrite(L_IN1_CH, 255);
    ledcWrite(L_IN2_CH, 255);

    ledcWrite(R_IN1_CH, 255);
    ledcWrite(R_IN2_CH, 255);

    state.leftMotorPwm = 0;
    state.rightMotorPwm = 0;
}

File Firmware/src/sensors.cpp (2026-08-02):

#include <Arduino.h>

#include <Wire.h>
#include <Adafruit_INA219.h>
#include <Adafruit_VL53L0X.h>

#include <sensors.h>

Adafruit_INA219 ina219;
Adafruit_VL53L0X tof;

constexpr int SDA_PIN = 7;
constexpr int SCL_PIN = 15;

bool initializeSensors(DriveWireState& state) {

    // initalize I2C bus with custom pins
    if (!Wire.begin(SDA_PIN, SCL_PIN)) { 
        
        state.ina219Online = false;
        state.tofOnline = false;

        return false;
    }

    // start both sensors

    bool ina219Status = ina219.begin();

    bool tofStatus = tof.begin();

    // update online status'

    state.ina219Online = ina219Status;
    state.tofOnline = tofStatus;


    return (ina219Status && tofStatus);

}

// updates the current, voltage and power telemetry
bool refreshElectricalTelemetry(DriveWireState& state) {

    // important values
    float busVoltage = 0;
    float currentmA = 0;
    float shuntVoltage_mV = 0;
    float batteryVoltage = 0;
    float systemPower = 0;


    // reading status'
    bool busVoltageSuccess = false;
    bool shuntVoltageSuccess = false;
    bool currentSuccess = false;

    bool refreshSuccess = false;

    // refresh the system voltage
    busVoltage = ina219.getBusVoltage_V();
    busVoltageSuccess = ina219.success();

    if (!busVoltageSuccess) {
        state.ina219Online = false;
        return false;
    } // report error instead of checking the others

    shuntVoltage_mV = ina219.getShuntVoltage_mV();
    shuntVoltageSuccess = ina219.success();

    if (!shuntVoltageSuccess) {
        state.ina219Online = false;
        return false;
    }

    // important to test which side the shunt voltage is actually on to know sign in this equation
    batteryVoltage = busVoltage + (shuntVoltage_mV / 1000);


    // refresh the system current
    currentmA = ina219.getCurrent_mA();
    currentSuccess = ina219.success();

    if (!currentSuccess) {
        state.ina219Online = false;
        return false;
    }


    // refresh system power, doesnt really need to be in an if statement anymore

    if (busVoltageSuccess && shuntVoltageSuccess && currentSuccess) {
        systemPower = batteryVoltage * currentmA;

        refreshSuccess = true;
    }

    // final function success output
    if (refreshSuccess) {

        state.batteryVoltageV = batteryVoltage;
        state.currentMa = currentmA;
        state.powerMw = systemPower;

        state.ina219Online = true;
        return true;
    } else {
        state.ina219Online = false;
        return false;
    }

}


// distance ToF telemetry
bool refreshDistanceTelemetry(DriveWireState& state) {

    // a type of measurement struct
    VL53L0X_RangingMeasurementData_t measure;
    uint16_t distance = 0;

    VL53L0X_Error status = tof.rangingTest(&measure, false);

    if (status != VL53L0X_ERROR_NONE) {
        state.tofOnline = false;
        return false;
    }

    if (measure.RangeStatus == 0) { 
        distance = measure.RangeMilliMeter;
        state.distanceMm = distance;

        state.tofOnline = true;
        return true;

    } else {
        state.tofOnline = true;
        return false;
    }

}


// convenience function - refreshes everything at once

bool refreshAllSensors(DriveWireState& state){ 

    // note that currently one could succeed, and then one telemetry point is updated and one isnt
    bool electricalState = refreshElectricalTelemetry(state);
    bool tofState = refreshDistanceTelemetry(state);

    return (electricalState && tofState);

}


// based on my explicit INA219 reading test using only Wire - only for testing

float getBusVoltage() {

    // getting the ESP32 ready to start by sending the INA219 address and a Write bit  
    Wire.beginTransmission(0x40);

    Wire.write(0x2); // queues the desired register to send to the INA219 (for bus voltage)

    Wire.endTransmission(false); // false tells ESP32 not to send STOP
    // this sends everything and gets ACK, returns transmission result

    if (Wire.requestFrom(0x40, 2) != 2) { return NAN; }
    // sends 0x40 again, and a read bit. Wants 2 bytes of data from the register.

    uint8_t MSB = Wire.read();
    uint8_t LSB = Wire.read();

    uint16_t MSB_shifted = (MSB << 8);  // bitshift MSB by 8 to make room for the LSB
    uint16_t rawBusVoltage = (MSB_shifted | LSB);

    uint16_t voltageCounts = (rawBusVoltage >> 3); // shave off the status bits

    float busVoltage = (voltageCounts * 0.004); // multiply the voltage count by 4 mV for total

    return busVoltage;  
}

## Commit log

2026-07-24 Update BuildLog with July 24th progress details
    Documented firmware completion for motors and test results.
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2026-07-30 Fix motor noise by updating PWM frequency configuration
    Replaced implicit PWM configuration with explicit LEDC setup to address audible motor noise during low duty cycles. Selected a PWM frequency of 17.5 kHz to eliminate noise while maintaining motor performance.
2026-07-30 Refactor motor control for PWM frequency and noise fix
    Updated motor control implementation to use explicit LEDC configuration for PWM frequency testing. Ensured compatibility with Arduino-ESP32 core 2.0.17 and preserved 8-bit resolution for existing commands.
2026-07-30 Fix audible motor noise by updating PWM frequency
    Investigated and resolved audible motor noise during low duty PWM operation by updating the PWM frequency configuration. Replaced implicit PWM setup with explicit LEDC configuration to support a higher frequency while maintaining 8-bit resolution.
2026-07-30 Revise June 29 debugging entry with resolution note
    Updated the June 29 entry to indicate resolution and added a note about ongoing debugging for the second motor issue.
2026-07-30 Revise title and details for PWM frequency testing
    Updated section title for PWM frequency testing and clarified the investigation into audible motor noise.
2026-07-30 Clarify PWM adjustments in debugging notes
    Updated the debugging notes to clarify PWM adjustments and results.
2026-08-01 Started sensors.cpp
    built sensors.h, and begain sensors.cpp. Got initializing and INA219 related functions built.
2026-08-01 Update BuildLog with sensor development details
    Documented progress on sensor implementation for telemetry.
2026-08-01 Fix formatting in BuildLog.md for sensor file names
2026-08-01 Fix formatting for sensors.h and sensors.cpp mention
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2026-08-01 Update BuildLog with INA219 sensor firmware details
    Documented the addition of INA219 sensor firmware and testing.
2026-08-01 Update BuildLog with INA219 fault test details
    Documented test for INA219 sensor fault functionality, including images and results.
2026-08-01 Updated INA219 Fault and Test
    Now immediately returns false after first failed poll, and test now shows values previous to sensor failure remain saved
    [main.cpp, sensors.cpp]
2026-08-01 Enhance refreshElectricalTelemetry() error handling
    Updated sensors.cpp to improve error handling in refreshElectricalTelemetry() and modified test file to retain values before sensor failure.
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2026-08-02 Update Debugging.md with distance telemetry notes
    Documented findings on distance telemetry loop behavior after sensor reconnection.
2026-08-02 Update debugging notes for distance telemetry sensor
    Clarified the issue with distance telemetry sensor reconnection and proposed a potential solution for handling offline sensors.
2026-08-02 Rename Distance Telemetry Loop to Offline Loop
    Updated section title and clarified sensor behavior after power cycling.
2026-08-02 Update debugging notes on sensor initialization
    Added observations about I2C initialization and INA219 sensor behavior.
2026-08-02 Update BuildLog with ToF telemetry test results
    Tested ToF telemetry with valid and invalid measurements, confirmed status updates. Noted differences between INA219 and VL53L0X during power reconnection.
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2026-08-11 Added Hardware Altium Files
    [DriveWirePCBLib.PcbLib, DriveWire_V1_Spin1.PrjPcb, ESP32.SchDoc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]
2026-08-11 added existing mechanical CAD
    [DriveWireStand.SLDPRT, DriveWireStand.STL, DriveWireStandv2.SLDPRT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]
2026-08-11 Update BuildLog with changes to main.cpp and new folders
    Updated main.cpp for serial operation and FreeRTOS. Added Hardware and Mechanical CAD folders with PCB and CAD files.
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2026-08-13 sensorTask RTOS fixes
2026-08-13 safety measure for failed queue creation
    [main.cpp]
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2026-08-13 sensorTask RTOS complete
    Safety added for failed task creation
    [main.cpp]
2026-08-13 Update BuildLog with RTOS task implementation details
    Added details about the implementation of the first RTOS task in DriveWire, including sensor updates and data handling improvements.
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2026-09-12 Added INA219BIDR
    Still need to add surrounding circuitry and shunt design.
    [Power.SchDoc]
2026-09-13 Add note on max current for shunt resistor selection
    Added a note about determining the expected max current for shunt resistor selection.
2026-09-13 INA219 Tentative Circuitry Added
    [Power.SchDoc]
2026-09-13 LiPo Stall Current Test
    [Power.SchDoc]
2026-09-13 Update BuildLog with RTOS task and INA219 details
    Documented the implementation of the first RTOS task in DriveWire with FreeRTOS, added INA219BIDR chip details, and described the main VBAT_BUS circuitry. Included test results for system stall current with a new 2S LiPo pack.
2026-09-13 Update BuildLog with battery performance observations
    Added notes on battery voltage sag and stall current readings for future reference.
2026-09-13 Update BuildLog with YouTube video link
    Added a link to a YouTube video of the stall current test.
2026-09-13 Power.sch updates and more
    [Power.SchDoc]
2026-09-13 Update image and add testing details in BuildLog.md
    Updated image reference in BuildLog.md and added details about testing the system stall current.
2026-09-14 Update BuildLog with September 14 test results
    Retested stall current with LiPo pack and measured power rails to confirm voltage drop reasons.
2026-09-14 Update Debugging.md with stall current test results
    Documented findings from testing stall current with a new 2S LiPo battery, including telemetry values and observations about battery voltage sag during tests.
2026-09-14 Add note on OV2 battery voltage interlock system
    Added a note about considering an OV2 battery voltage interlock system with a MOSFET and microcontroller control.
2026-09-14 Hardware Updates
    [Power.SchDoc]
2026-09-15 Stall Current Plot Stuff MATLAB
2026-09-15 Update BuildLog with telemetry changes and stall current plot
    Decreased INA219 telemetry period and updated main.cpp for stall current plotting. Included a plot in MATLAB with relevant files.
2026-09-15 Tentative Power Schematic
    [Power.SchDoc]
2026-09-15 Update BuildLog with Power schematic details
    Added completed Power schematic with tentative values and an image.
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2026-09-22 Schematic Updates and Datasheet
    [6V_buck.SchDoc, Power.SchDoc]
2026-09-22 Document circuit design for 6V buck converter
    Added entry for September 22 detailing circuit design and schematic.
2026-09-23 6V Buck updates
    [6V_buck.SchDoc]
2026-09-23 name change
    [buck_converters.SchDoc]
2026-09-23 Buck updates
    [DriveWire_V1_Spin1.PrjPcb, buck_converters.SchDoc]
2026-09-25 Footprint and modelling work
    [DriveWirePCBLib.PcbLib, SchemLib.SchLib, buck_converters.SchDoc]
2026-09-25 Document progress on 6V buck converter schematic
    Added details about the 6V buck converter schematic design, including component choices and design considerations.
2026-09-25 Add September 25 entry to BuildLog
    Documented inductor selection criteria and custom footprint creation for 6V buck design.
2026-09-25 footprint inductor custom
    [DriveWirePCBLib.PcbLib]
2026-09-25 Hardware changes
    [DriveWirePCBLib.PcbLib, buck_converters.SchDoc]
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2026-10-11 Update BuildLog with October 10-11 entries
    Documented design decisions for 6 V and 3.3 V buck converters.
2026-10-11 Update BuildLog with current limit for 3.3 V buck
    Added current limit determination for the 3.3 V buck.
2026-10-11 Update BuildLog with Raspberry Pi integration notes
    Added notes on Raspberry Pi integration and buck breakout board design considerations.
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2026-10-11 Update BuildLog with integration plans and buck converter status
    Added details about Raspberry Pi integration and completion of the 3.3 V buck converter.
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2026-10-15 Net label fixes and starting logic power mux
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2026-10-15 Update BuildLog with ESP32 schematic details
    Documented the completion of the ESP32 schematic with detailed features and added information about the power mux design.
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2026-10-16 Schematic Fixes
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2026-10-20 docs: replace October 19 buck layout image
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2026-10-24 Update BuildLog with FreeRTOS motor task details
    Added FreeRTOS motor task with command queue and test for PWM control.
2026-11-01 Update BuildLog with PCB assembly details
    Documented progress on DriveWire PCB assembly and measurements.
2026-11-01 Add image for November 1 PCB soldering entry
    Added an image of the PCB soldering process to the build log.
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2026-11-05 Clarify motor-supply stall run measurements
    Updated the description of the motor-supply stall run to clarify that the motors were set back to coast after measurements were taken.
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
